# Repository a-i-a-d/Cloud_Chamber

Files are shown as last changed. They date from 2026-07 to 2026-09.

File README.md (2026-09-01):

# Peltier based Cloud Chamber

<p float="left">
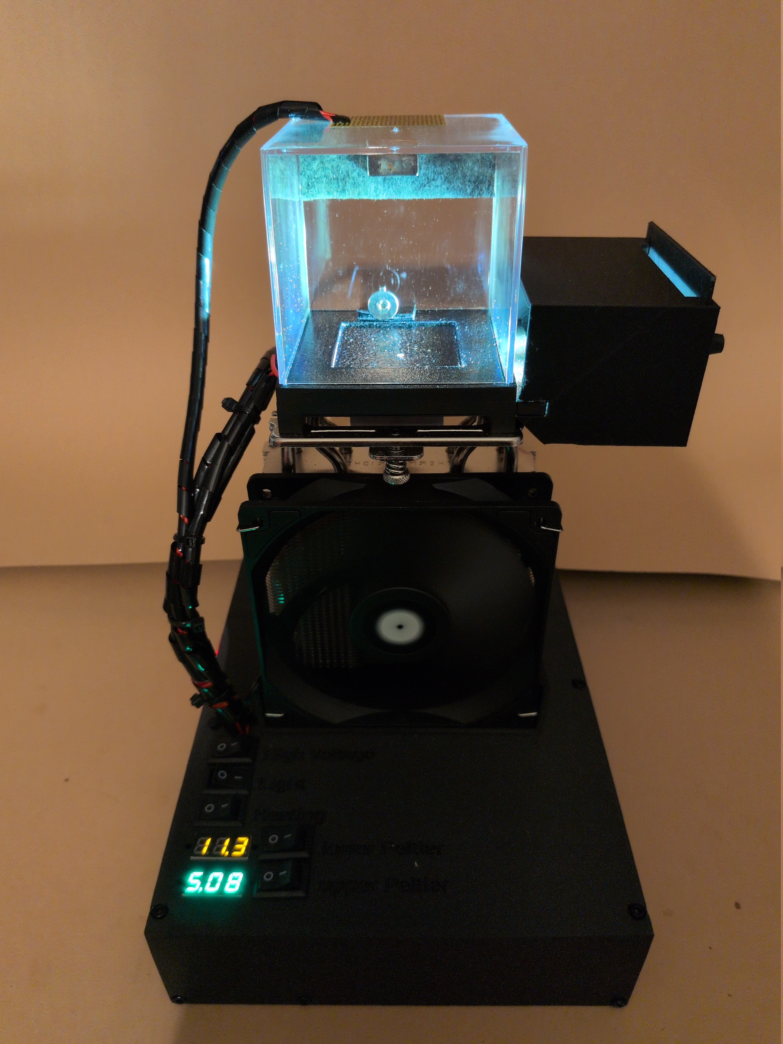
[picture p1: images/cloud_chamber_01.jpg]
 
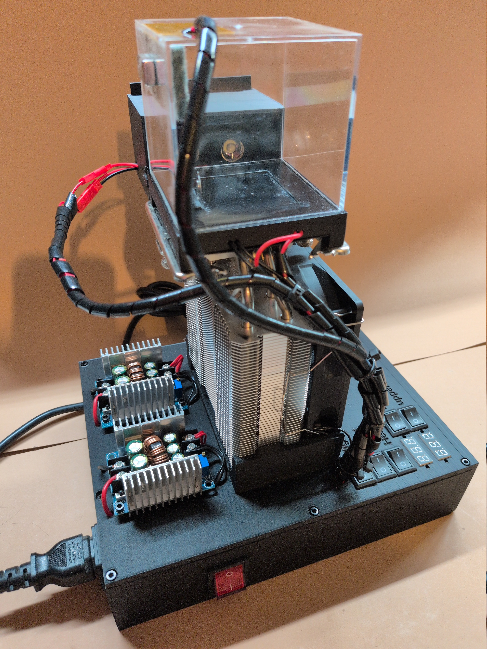
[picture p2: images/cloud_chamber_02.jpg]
 
</p>

This project is the documentation on how I built a Peltier element based cloud chamber. The motivation came from having most of the required parts laying around, and since it works quite well, here are instructions on how it is made.

## WARNING

__This project requires to work with 220V, which can be deadly. Do not attempt to build it if you are not familiar in dealing with mains voltage!__

## Important Notes

- The Peltier elements I used did not consume the wattage according to the specs, so I assume them to be of inferior quality, and therefore will not provide links to where I got them. They do the job, but if they would work according to specs, they should provide even greater cooling.
- This project was not planned, but rather built as a proof of concept to see if the concept works at all, so there are many things that can be improved or changed, e.g. less glueing.
- I did not make use of a high voltage field, it did not seem necessary but might be added at some point in the future. Everything is prepared for it (switch, location for power adapter), so it shouldn't be hard to add it.
- Pictures in this document were taken at different build stages and might not be fully accurate, since I added e.g. the light part later on.

## Table of Contents

- [Parts](https://github.com/a-i-a-d/Cloud_Chamber#parts)
  - [To be Bought](https://github.com/a-i-a-d/Cloud_Chamber#to-be-bought)
  - [To be Printed](https://github.com/a-i-a-d/Cloud_Chamber#to-be-printed)
  - [Other Things Required](https://github.com/a-i-a-d/Cloud_Chamber#other-things-required)
- [Power Schematics](https://github.com/a-i-a-d/Cloud_Chamber#power-schematic)
- [Assembly](https://github.com/a-i-a-d/Cloud_Chamber#assembly)
  - [1. Case Bottom](https://github.com/a-i-a-d/Cloud_Chamber#1-case-bottom)
  - [2. Adjust Voltages](https://github.com/a-i-a-d/Cloud_Chamber#2-adjust-voltages)
  - [3. Case Cover - Under Side](https://github.com/a-i-a-d/Cloud_Chamber#3-case-cover---under-side)
  - [4. Case Cover - Upper Side](https://github.com/a-i-a-d/Cloud_Chamber#4-case-cover---upper-side)
  - [5. Assemble Cooling Tower](https://github.com/a-i-a-d/Cloud_Chamber#5-assemble-cooling-tower)
  - [6. Add Heating Element](https://github.com/a-i-a-d/Cloud_Chamber#6-add-heating-element)
  - [7. Add lights](https://github.com/a-i-a-d/Cloud_Chamber#7-add-lights)
  - [8. Attach Cooling Tower](https://github.com/a-i-a-d/Cloud_Chamber#8-attach-cooling-tower)
  - [9. Connect Cooling Tower](https://github.com/a-i-a-d/Cloud_Chamber#9-connect-cooling-tower)
  - [10. Connect Case Cover to Bottom](https://github.com/a-i-a-d/Cloud_Chamber#10-connect-cover-to-bottom)
- [Usage]()
  - [Adjust Peltier Voltage]()
  - [Prepare Chamber]()
  - [Running the system]()
- [Notes](https://github.com/a-i-a-d/Cloud_Chamber#notes)

# Parts

## To be bought

I had some parts laying around, but for the sake of completeness, I created a list with all parts and their price in Aug 2026 on Amazon.
The total value of the parts is about 250 Euro. Here a list with links.

| Part | Amazon Link | Image | Notes |
| --- | --- | --- | --- |
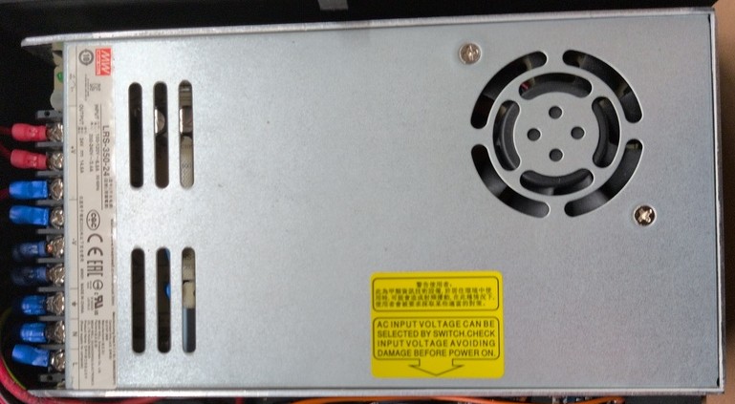
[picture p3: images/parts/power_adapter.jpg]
power-adapter
| Power adapter 220V->24V | [Amazon](https://www.amazon.de/Meanwell-Biltron-Schaltnetzteil-geschlossene-Struktur/dp/B07SVH2H3G/ref=sr_1_30) |  |  |
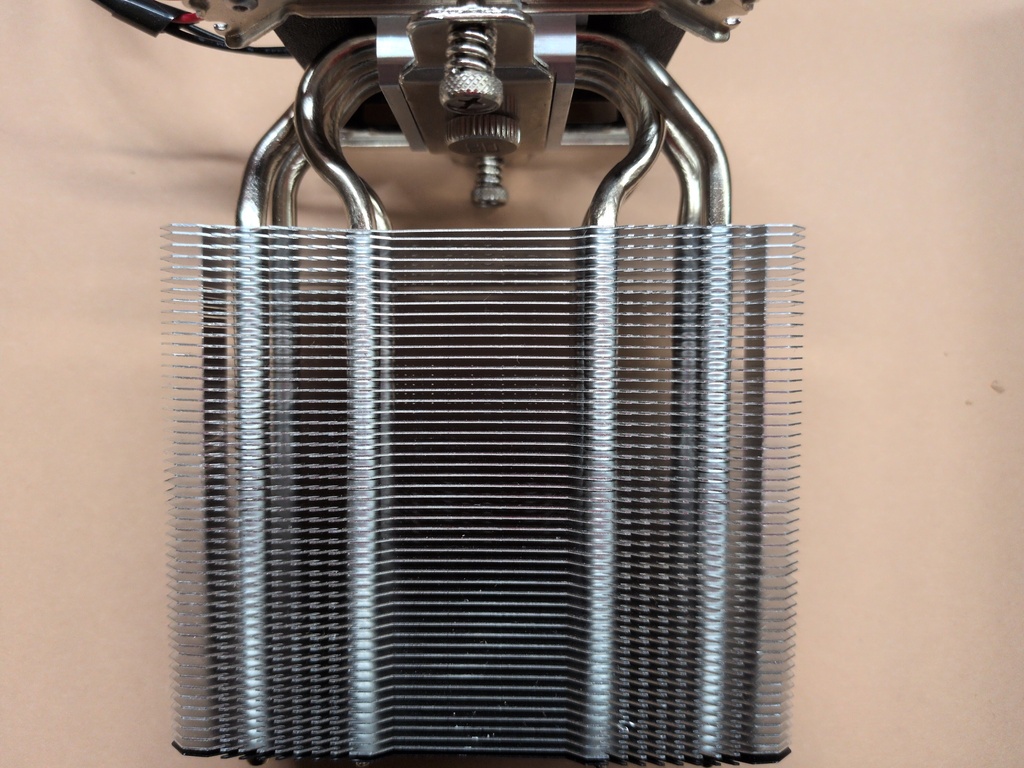
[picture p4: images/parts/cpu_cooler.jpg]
cpu-cooler
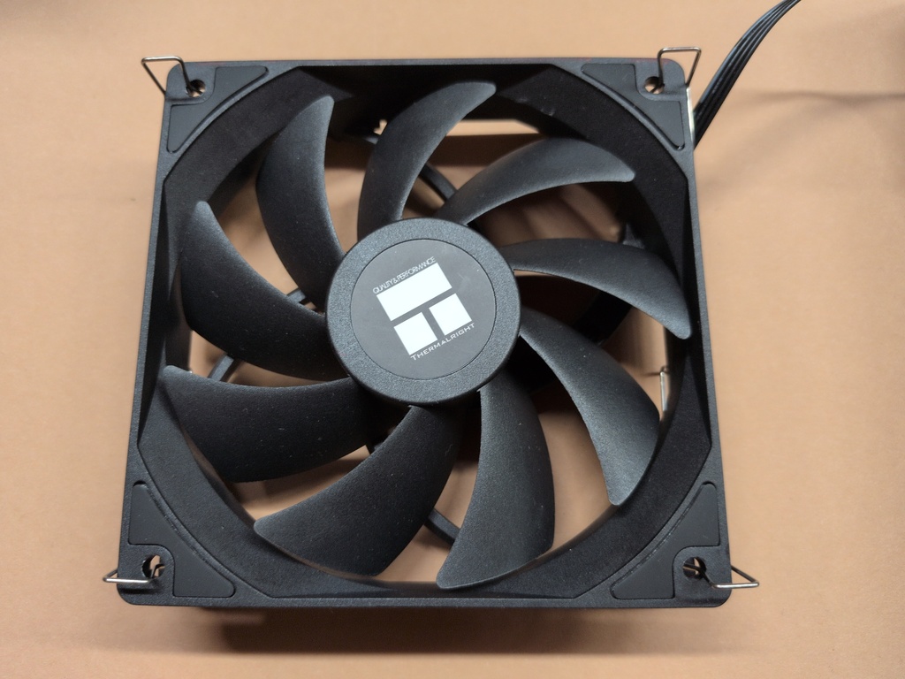
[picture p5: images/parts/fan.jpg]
fan
| 1x CPU Cooler with Fan | [Amazon](https://www.amazon.de/dp/B0FMRXDHD6?ref=ppx_yo2ov_dt_b_fed_asin_title&th=1) | <br> |  |
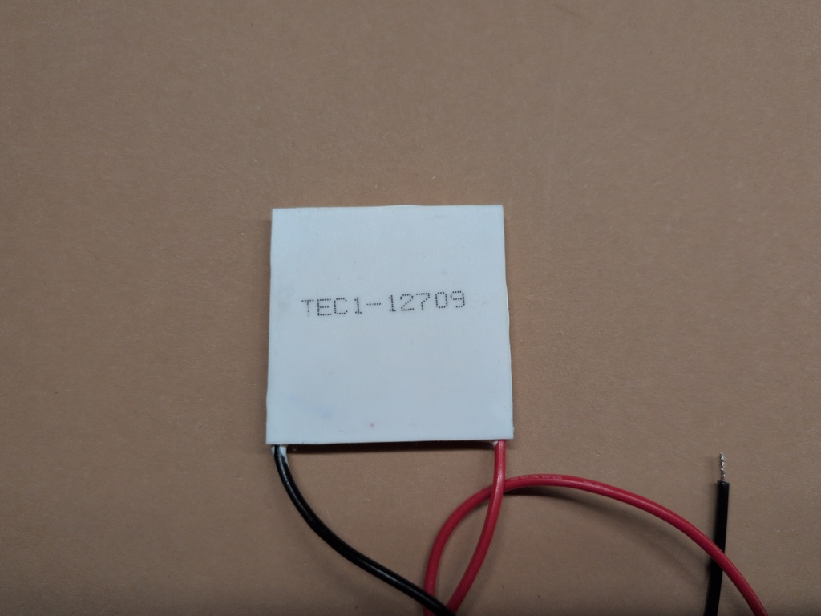
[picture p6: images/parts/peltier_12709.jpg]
peltier-12709
| 1x Peltier 12709 |  |  |  |
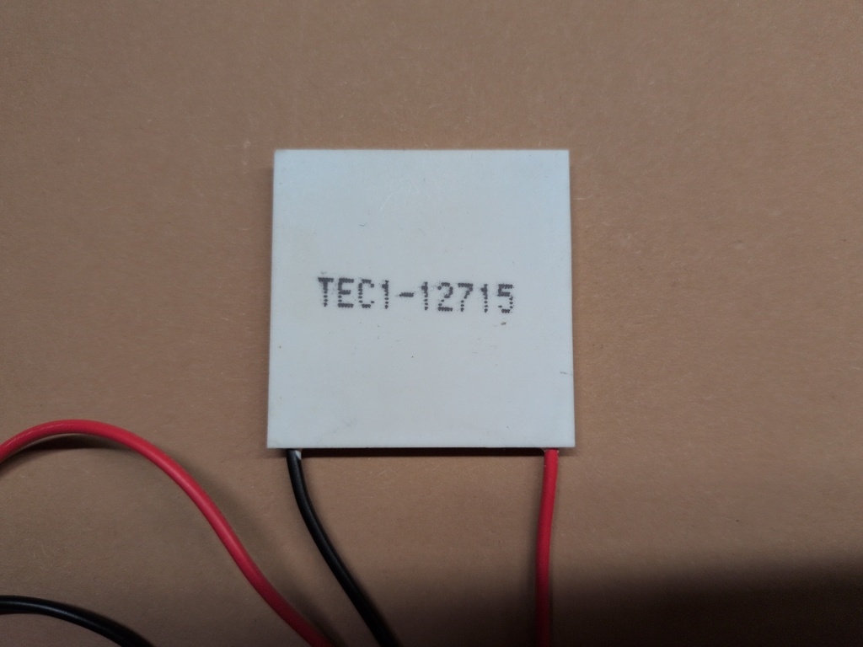
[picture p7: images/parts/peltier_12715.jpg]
peltier-12715
| 1x Peltier 12715 |  |  |  |
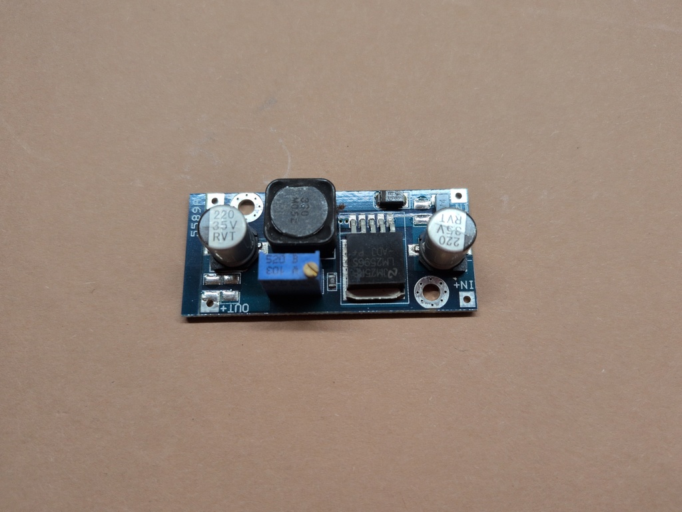
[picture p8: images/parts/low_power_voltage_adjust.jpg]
low-power-voltage-adjust
| 3x Low Power Voltage Converter | [Amazon](https://www.amazon.de/Yizhet-Stromversorgung-Abw%C3%A4rtswandler-Einstellbares-Abw%C3%A4rtsmodul/dp/B0823P6PW6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) |  |  |
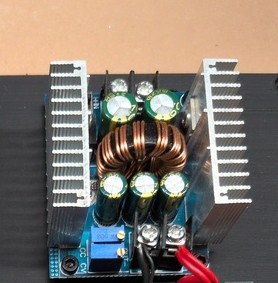
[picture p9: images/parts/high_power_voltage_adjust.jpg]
high-power-voltage-adjust
| 2x High Power Voltage Converter | [Amazon](https://www.amazon.de/dp/B09LLPQHCF?ref=ppx_yo2ov_dt_b_fed_asin_title) |  |  |
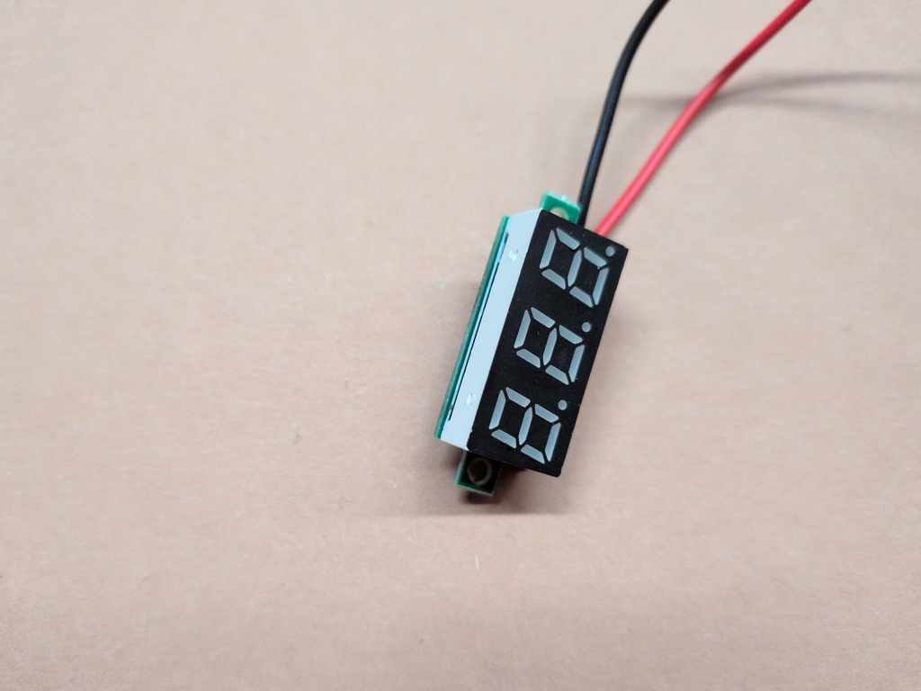
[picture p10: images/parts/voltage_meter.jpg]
voltage meter
| 2x simple voltage meters | [Amazon](https://www.amazon.de/dp/B082ZLRY1Y?th=1) |  |  |
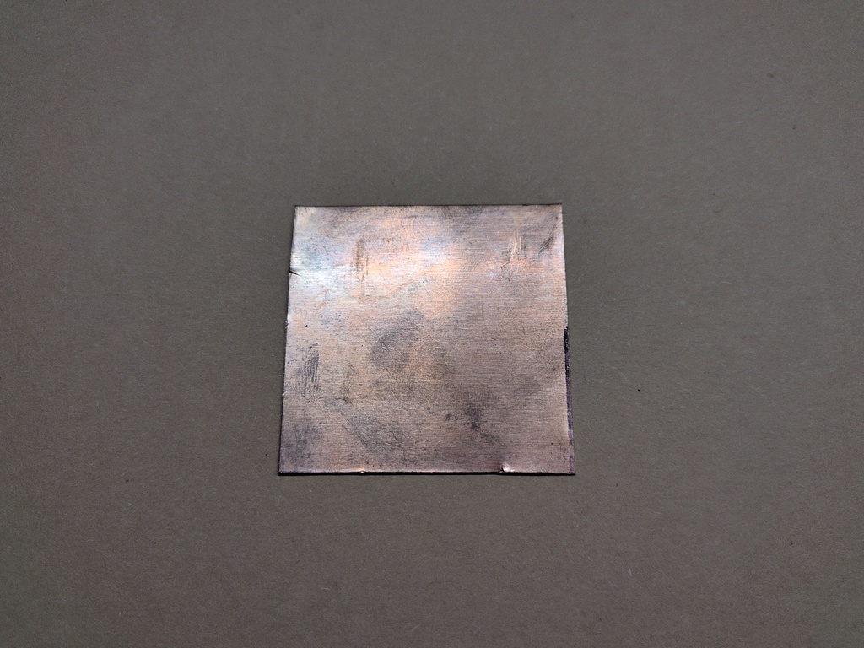
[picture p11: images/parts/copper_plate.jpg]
copper-plate
| Copper Plate 5x5x0.3cm | [Amazon](https://www.amazon.de/dp/B098RTDXQK?ref=ppx_yo2ov_dt_b_fed_asin_title&th=1) |  | The image is not of the actual part, but a thinner plate |
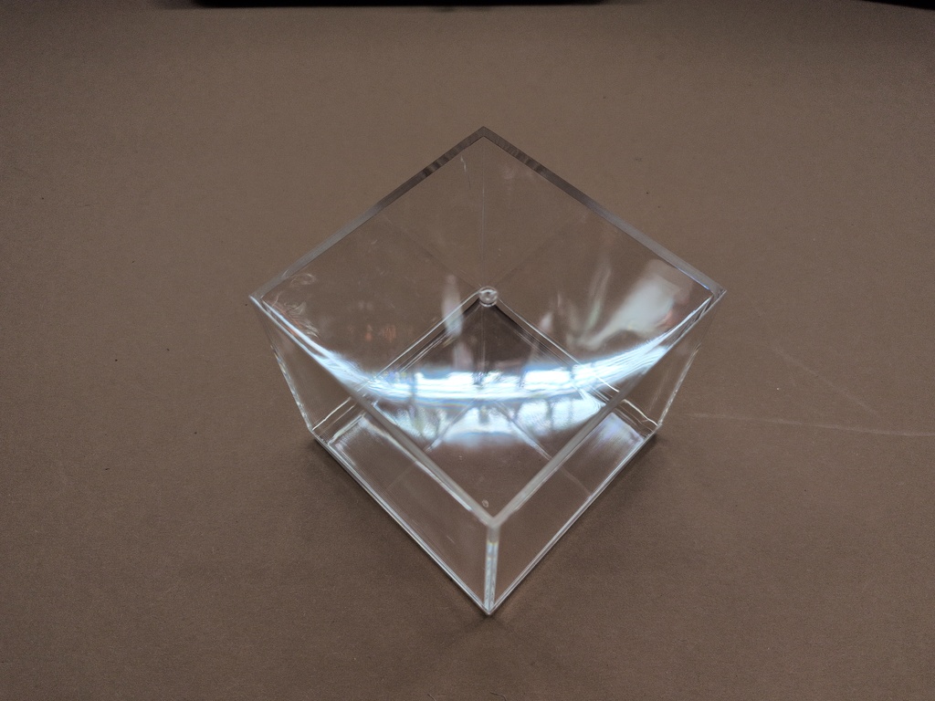
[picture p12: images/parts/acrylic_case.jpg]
acrylic-case
| Acrylic Case 8x8x8cm | [Amazon](https://www.amazon.de/Pilikoll-Transparent-Geschenkbox-transparentf%C3%BCr-Aufbewahrung/dp/B0FVSGY3C1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) |  |  |
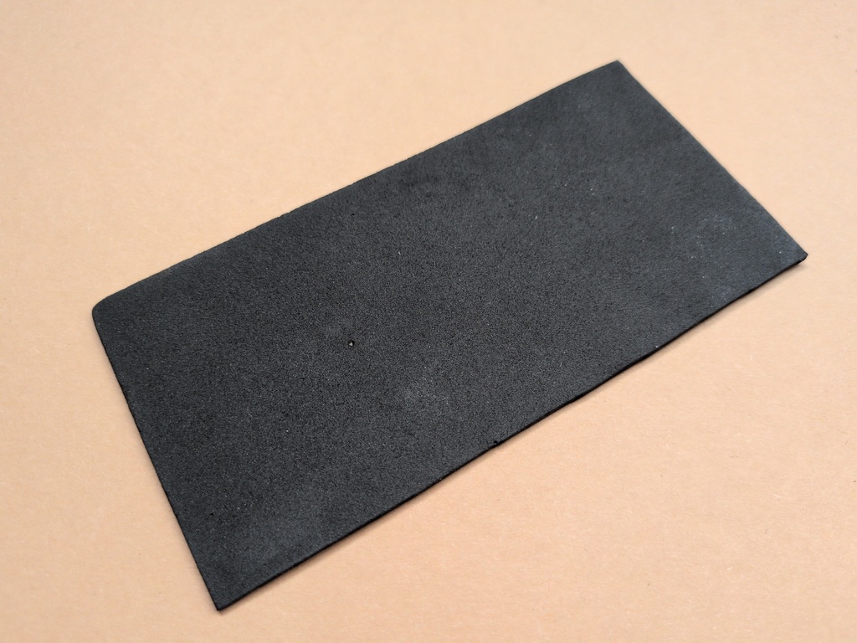
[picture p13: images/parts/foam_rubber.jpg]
foam-rubber
| Foam rubber 2mm | [Amazon](https://www.amazon.de/dp/B07JNZB8X1?ref=ppx_yo2ov_dt_b_fed_asin_title&th=1) |  |  |
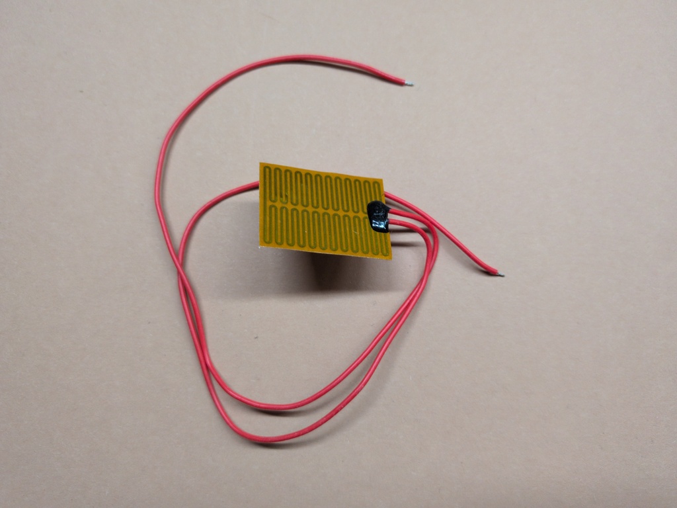
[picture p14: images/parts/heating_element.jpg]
heating-element
| Heating Element | [Amazon](https://www.amazon.de/dp/B0CTTNP7P9?ref=ppx_yo2ov_dt_b_fed_asin_title) |  |  |
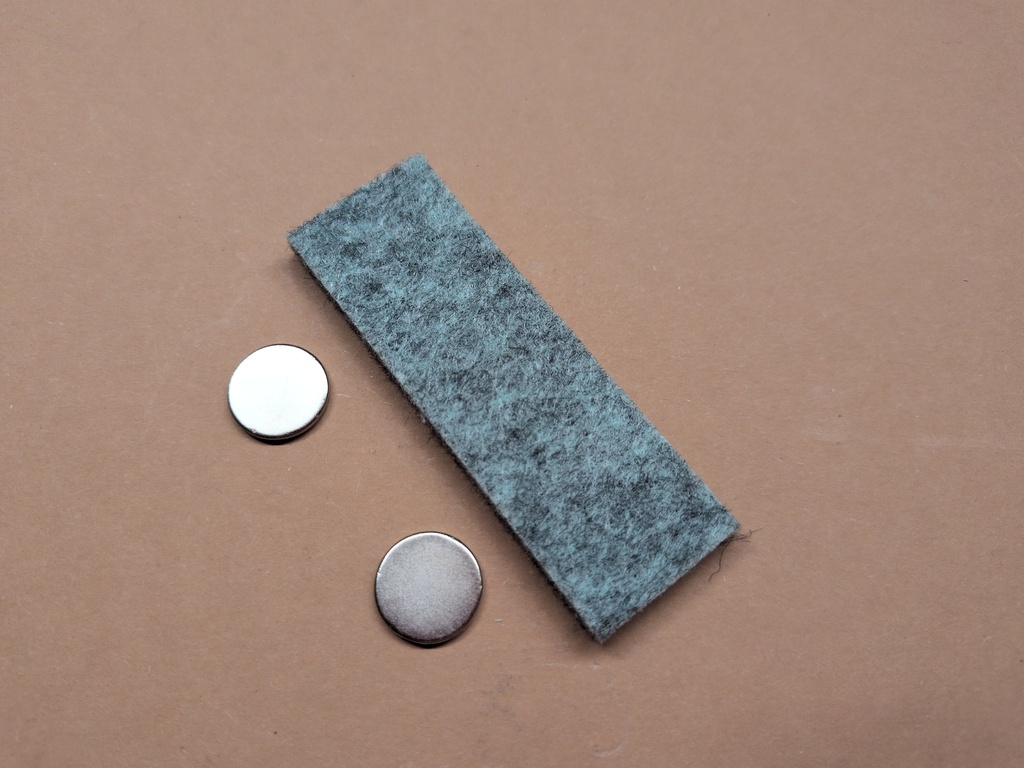
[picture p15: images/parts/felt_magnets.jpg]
felt-magnets
| Felt | [Amazon](https://www.amazon.de/dp/B00WLSX5QU?ref=ppx_yo2ov_dt_b_fed_asin_title&th=1) |  |  |
| Magnets | [Amazon](https://www.amazon.de/-/en/Wukong-Neodymium-Suitable-Whiteboards-Creative/dp/B0CP3N6QV3/ref=sr_1_36) | felt-magnets |  |
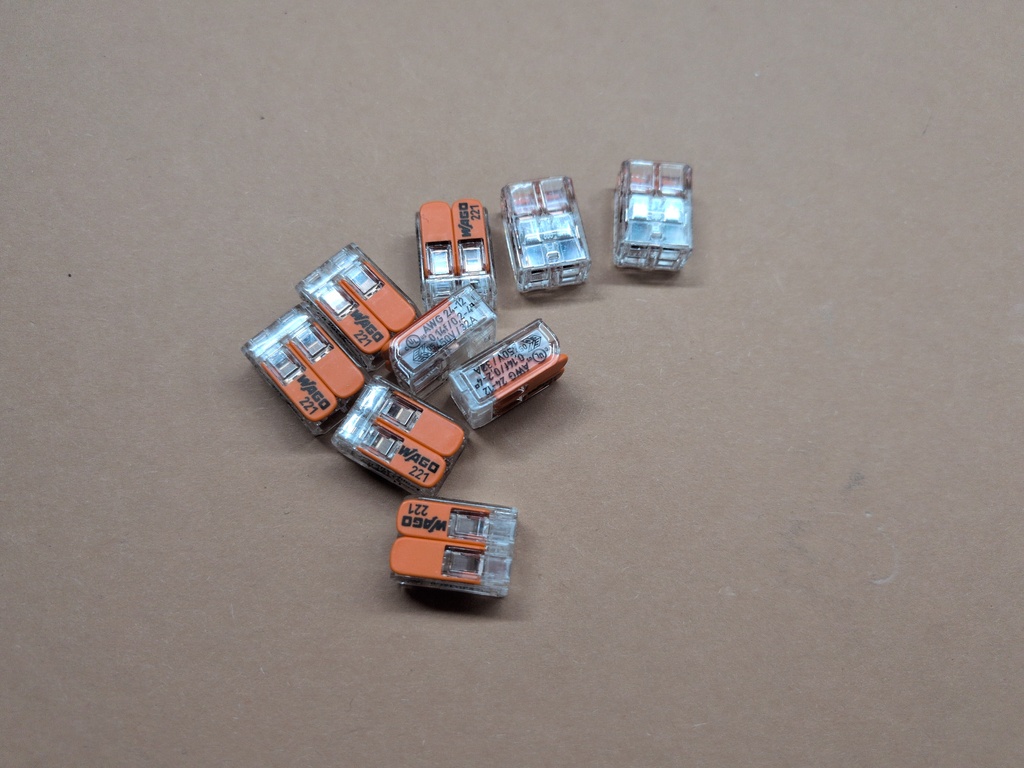
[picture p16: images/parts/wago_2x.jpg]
wago-2x
| 12x WAGO Connector 2x | [Amazon](https://www.amazon.de/Wago-221-412-996-016-Verbindungsklemme-flexibel/dp/B09VZYVWBX/ref=sr_1_3_mod_primary_new) |  |  |
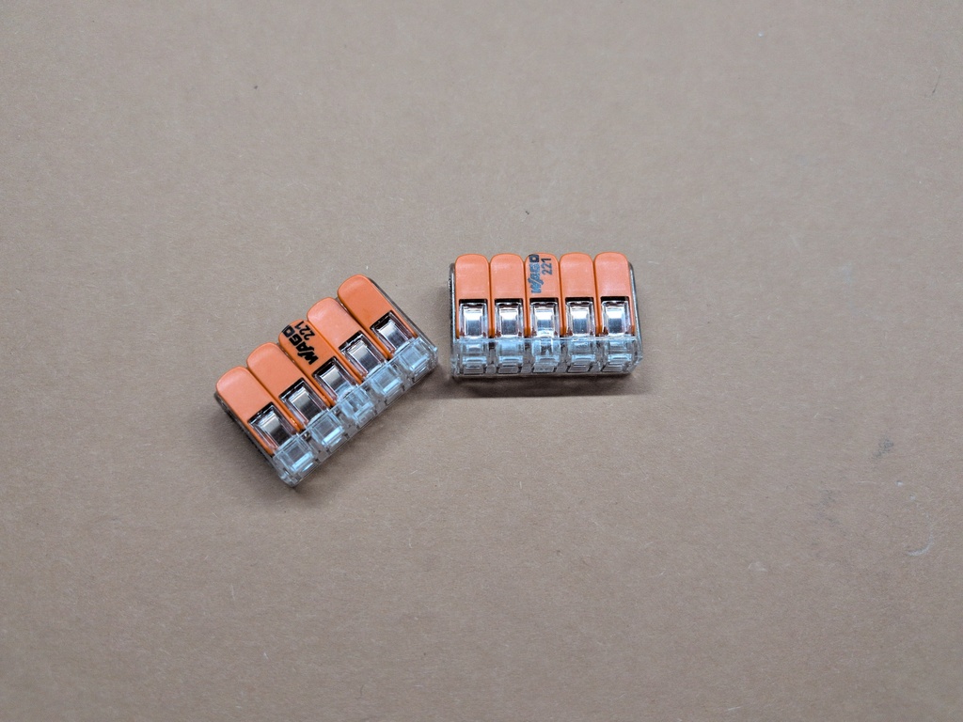
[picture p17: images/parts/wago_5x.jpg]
wago-5x
| 2x WAGO Connector 5x | [Amazon](https://www.amazon.de/Wago-221-415-Verbindungsklemme-5-Leiter-Bet%C3%A4tigungshebel/dp/B0107SYYGU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) |  |  |
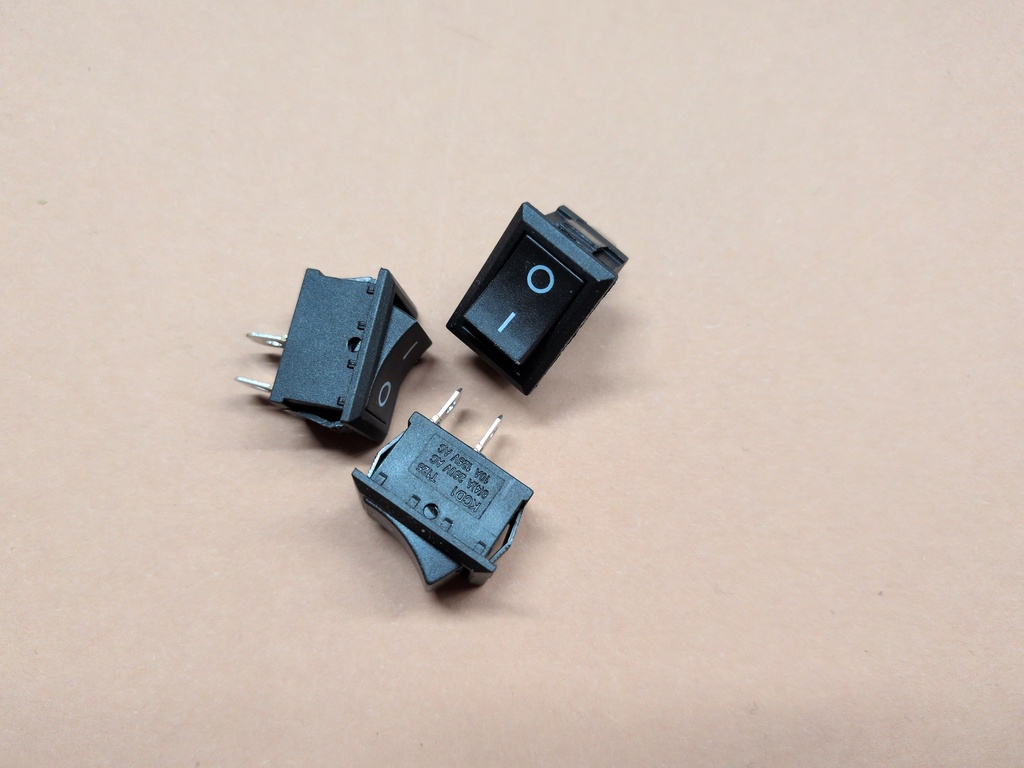
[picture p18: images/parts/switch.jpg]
switch
| 5x Low Power Switches | [Amazon](https://www.amazon.de/VUNIVERSUM-Kippschalter-Wippschalter-Schalter-Modellbau%C2%AE/dp/B07M5QMXDZ/ref=sr_1_16) |  |  |
| LED Spotlights | [Amazon](https://www.amazon.de/dp/B0F9GCK1NC?ref=ppx_yo2ov_dt_b_fed_asin_title) |  |  |
| Thermal pads | [Amazon](https://www.amazon.de/dp/B0B3N7184J?ref=ppx_yo2ov_dt_b_fed_asin_title) |  |  |
| 220V power switch | [Amazon](https://www.amazon.de/Miratic-Unterbeleuchtet-Kippschalter-Schalter-Versorgungsspannung/dp/B0CRBCK8T4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) |  |  |
| 220V power socket | [Amazon](https://www.amazon.de/PNGKNYOCN-IEC320-Stecker-Adapter-Sicherungshalter/dp/B0BWF5M677/ref=sr_1_3) |  |  |
| 6x Insulated flat connectors | | | |
| AWG 10 cable |  |  |  |
| AWG 16 cable |  |  |  |
| AWG 16 cable lugs |  |  |  |
| Insulated flat connectors |  |  |  |
| 4 Screws 4x8mm |  |  |  |
| x Screws 3x8mm |  |  |  |
| x Screws 3x12mm |  |  |  |
| x Screws 2x4mm |  |  |  |
| x Screws 2.5x5mm |  |  |  |
| 8x screw inserts M3x5x5 |  |  |  |
| Silicone |  |  |  |
| Black spray paint |  |  |  |
| Super glue |  |  |  |

## To be printed

All printed parts are openscad code, you can open them with openscad and then directly change variables at the beginning to adjust the screw diameter or part dimensions. Please note that I haven't tested changing them, so this might result in non printable models.

| Part | Image | Link | Notes | 
|---|---|---|---|
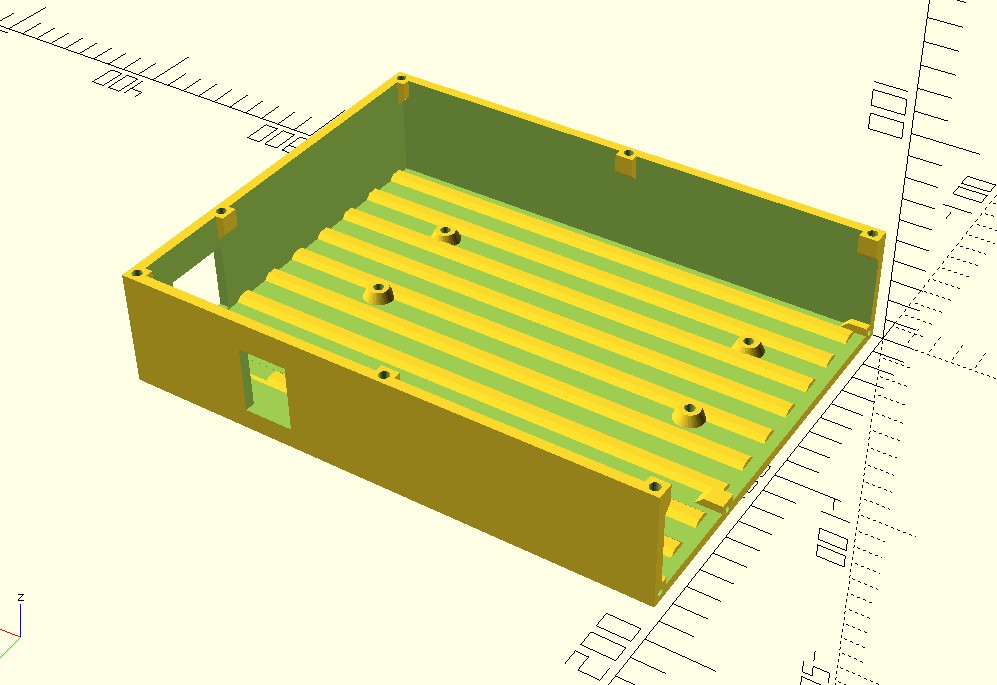
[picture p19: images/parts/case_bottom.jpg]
case-bottom
| Case Bottom |  | [stl](/stl/cloud_chamber_power_case-lower.stl) | best printed standing up with support |
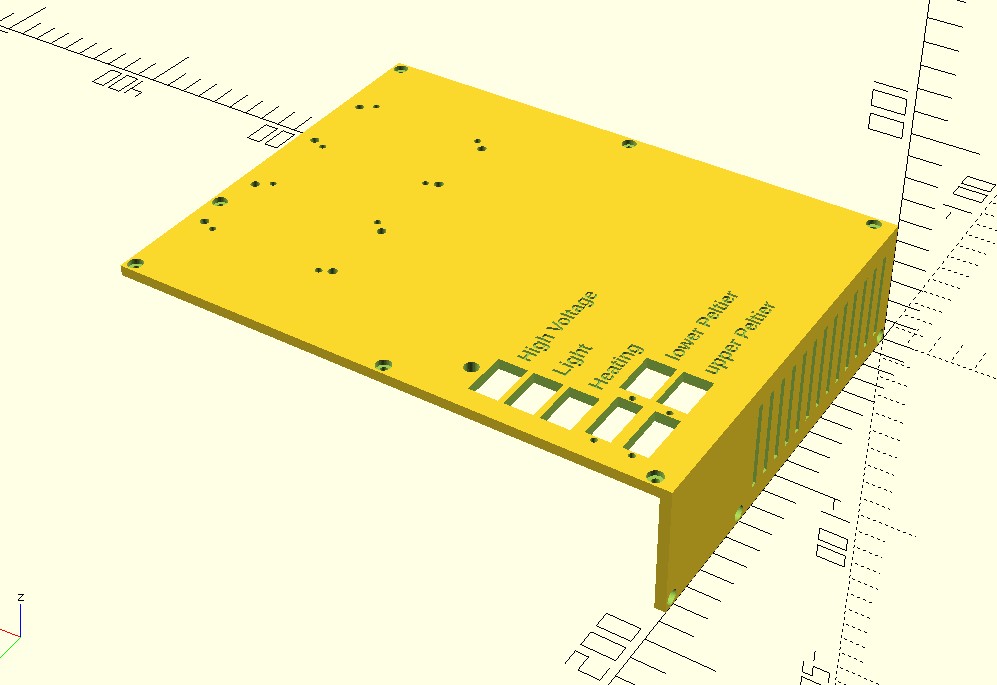
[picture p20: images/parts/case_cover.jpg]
case-cover
| Case Cover |  | [stl](stl/cloud_chamber_power_case-upper.stl) | best printed standing up with support |
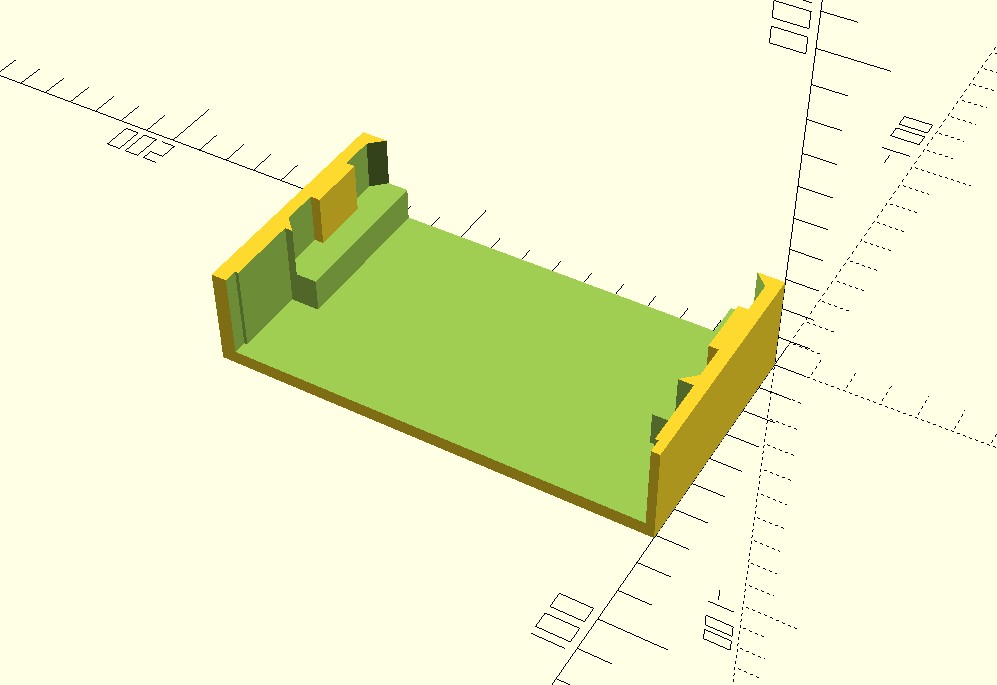
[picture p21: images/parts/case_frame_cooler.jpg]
case-cooler-frame
| Case Cooler Frame |  | [stl](stl/cloud_chamber_top.stl) | |
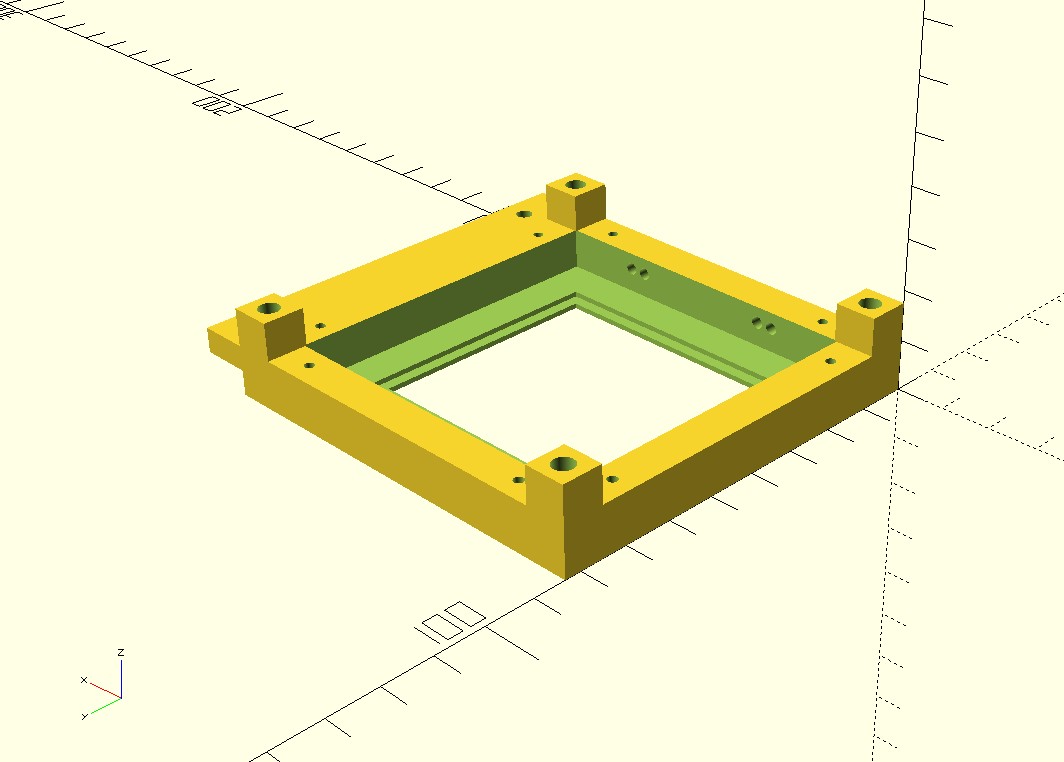
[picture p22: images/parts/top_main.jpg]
top-part
| Top Part |  | [stl](stl/cloud_chamber_cooling_plate-main_body.stl) | |
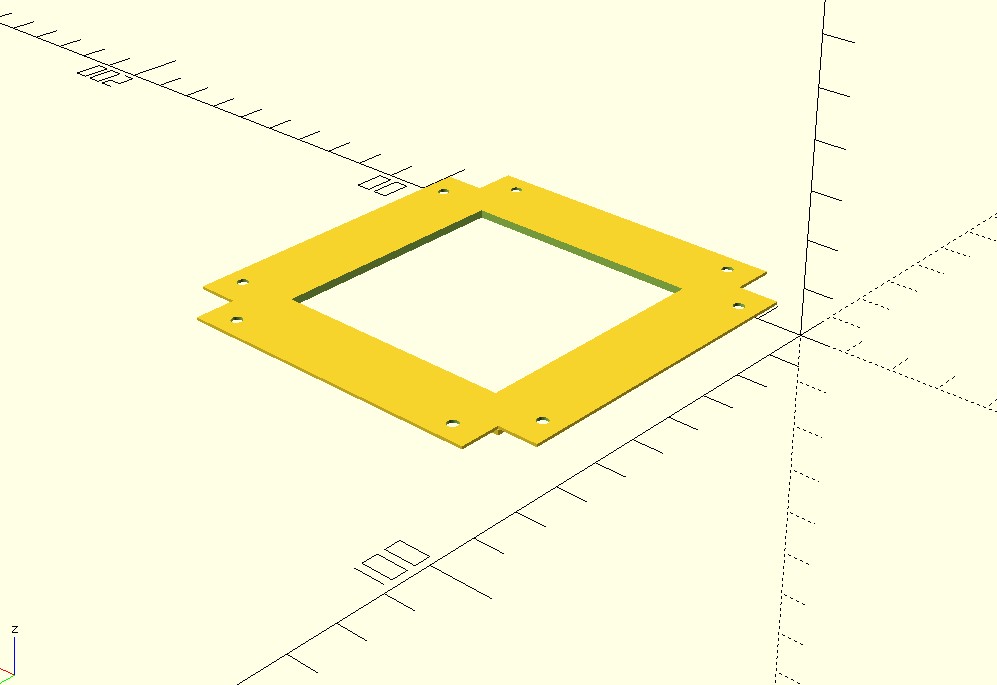
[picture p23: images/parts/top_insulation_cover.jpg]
top-insulation-cover
| Top Insulation Cover |  | [stl](stl/cloud_chamber_cooling_plate-insulation_top.stl) |  |
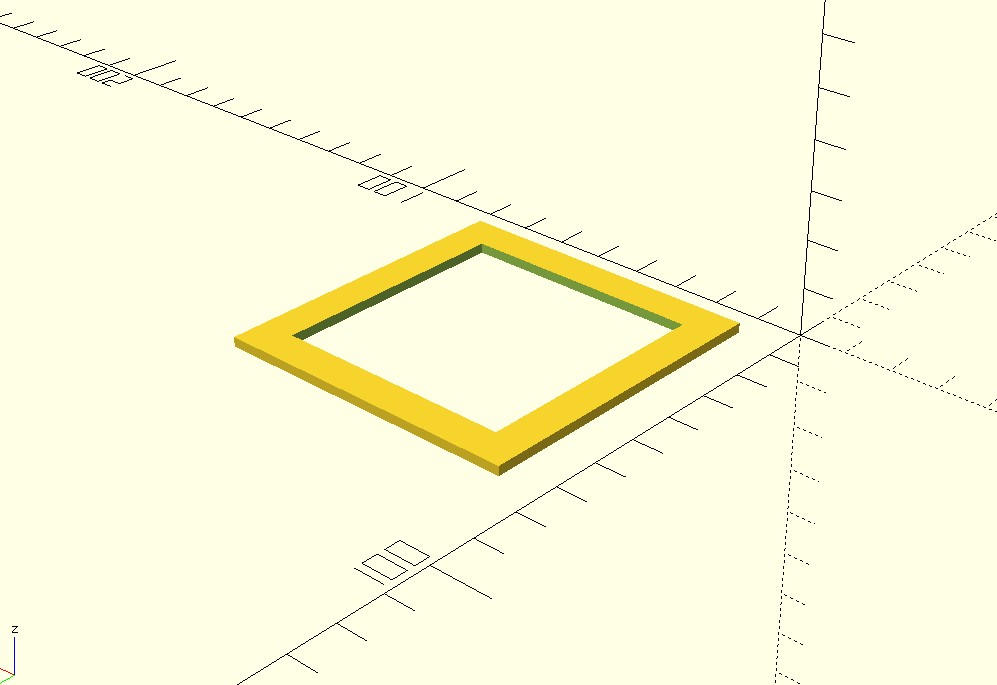
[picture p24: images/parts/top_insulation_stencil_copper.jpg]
top-insulation-stencil-copper
| Top Insulation Stencil Copper |  | [stl](stl/cloud_chamber_cooling_plate-insulation_stencil_coppr.stl) | optional part, only used as stencil for the insulation |
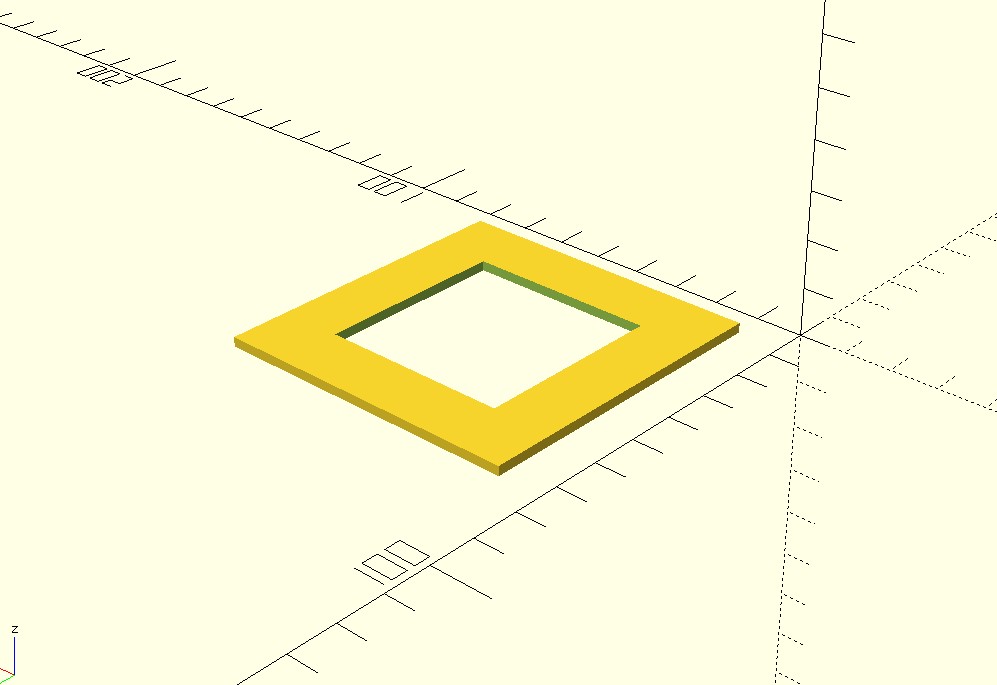
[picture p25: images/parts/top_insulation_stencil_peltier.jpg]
top-insulation-stencil-peltier
| Top Insulation Stencil Peltier |  | [stl](stl/cloud_chamber_cooling_plate-insulation_stencil_peltier.stl) | optional part, only used as stencil for the insulation |
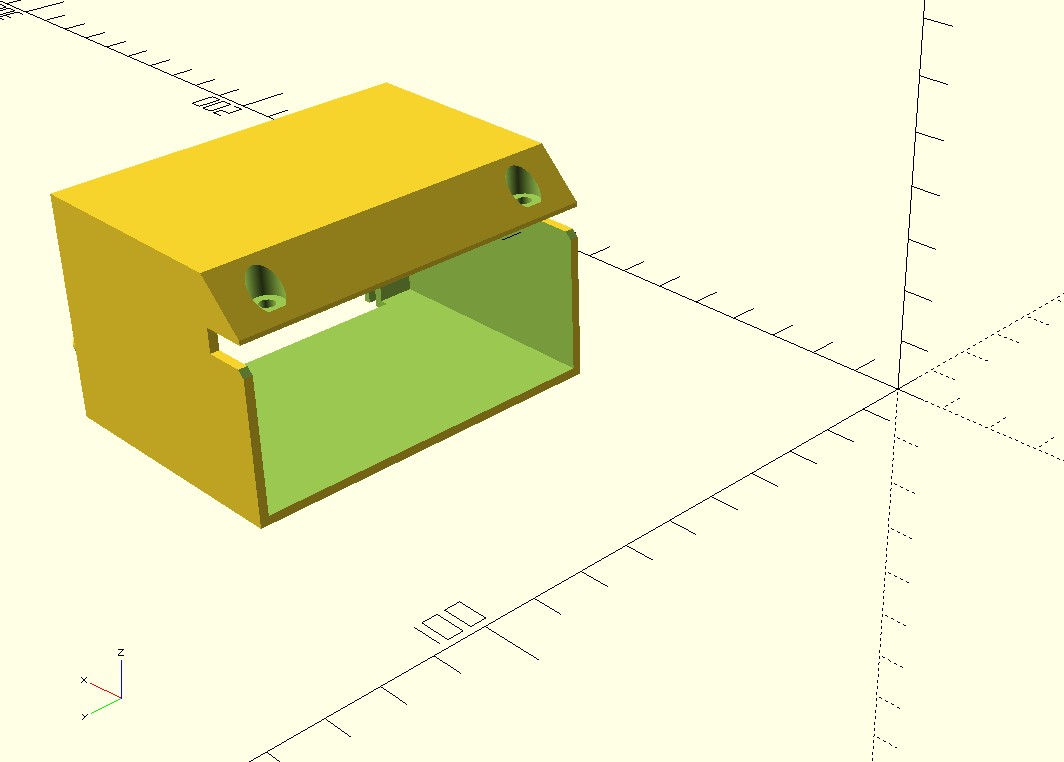
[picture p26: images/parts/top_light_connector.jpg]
light-connector
| Light Connector Box |  | [stl](stl/cloud_chamber_light_case.stl) | |
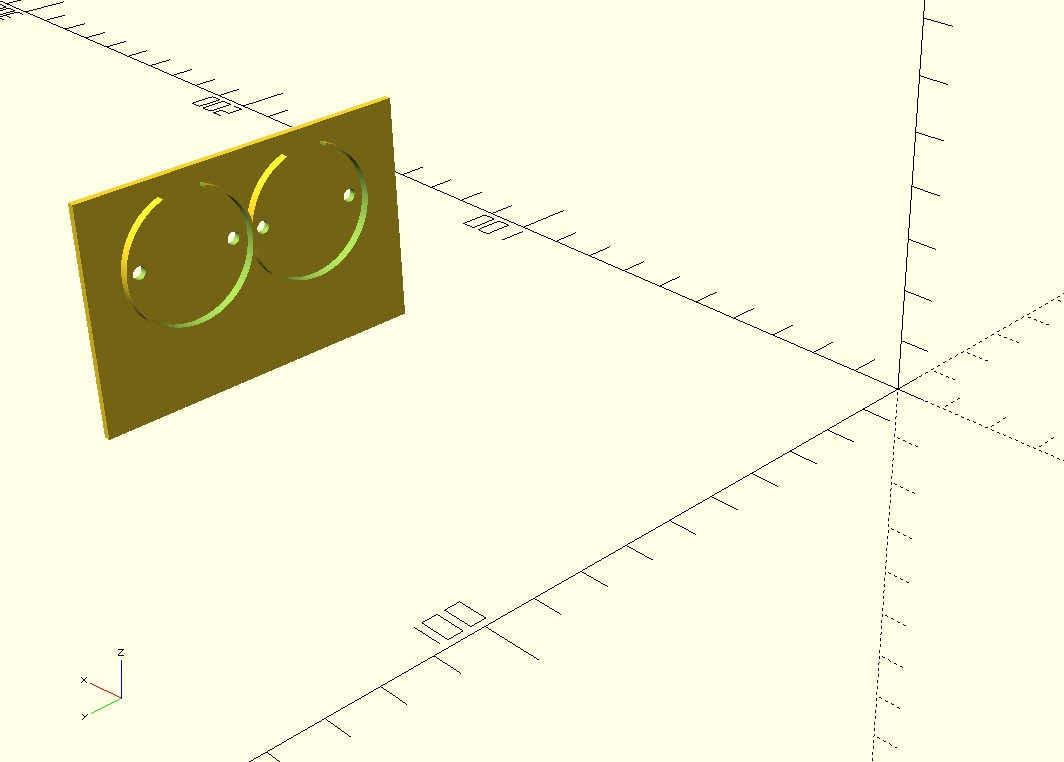
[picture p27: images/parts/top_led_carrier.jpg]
led-carrier
| LED Carrier |  | [stl](stl/cloud_chamber_led_carrier.stl) | |

## Other things required

- Voltage Meter - for adjusting the voltages<br>
- Soldering Iron, for soldering cables to the low power adapters, plugs and switches.

# Power Schematic
A simple diagram showing how everything gets connected. There is not much going on but voltage getting adjusted for different parts.<br>
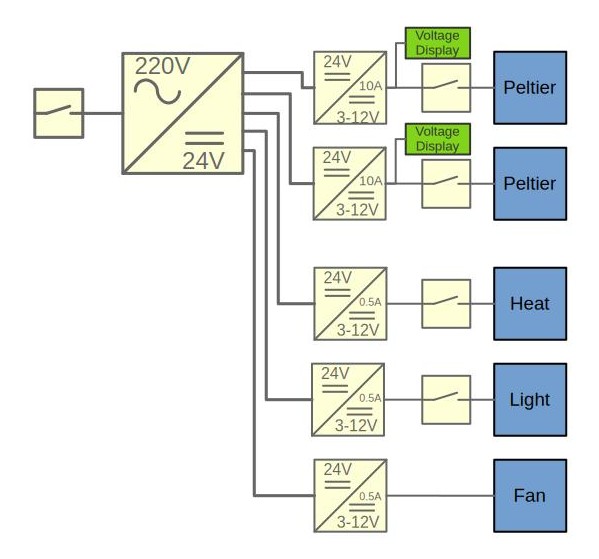
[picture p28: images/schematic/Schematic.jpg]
schematic


# Assembly
Once all parts are printed, the assembly is pretty much straight forward.

## 1. Case Bottom

__Note__: all connections with the 220V->24V voltage adapter have to be done with cable lugs. Don't screw in cables directly!

1.1 Prepare case
- insert the screw inserts into the screw holes of the bottom part of the case with a hot soldering iron.

1.2 Connect voltage adapter with 220V switch and socket
- Screw the 220V socket into the case
- Insert the 220V switch into the case
- Screw the power adapter into the bottom of the case with 4x8 mm screws from below
- Connect N (blue) and L (black) from the 220V socket to the 220V switch using insulated flat connectors and AWG 16 cables
- Connect N (blue) and L (black) from the 220V switch to the N and L connection on the 220V voltage adapter using insulated flat connectors and AWG 16 cables
- Connect E from the 220V socket to the E connection on the 220V voltage adapter using insulated flat connectors and a green-yellow AWG 16 cable
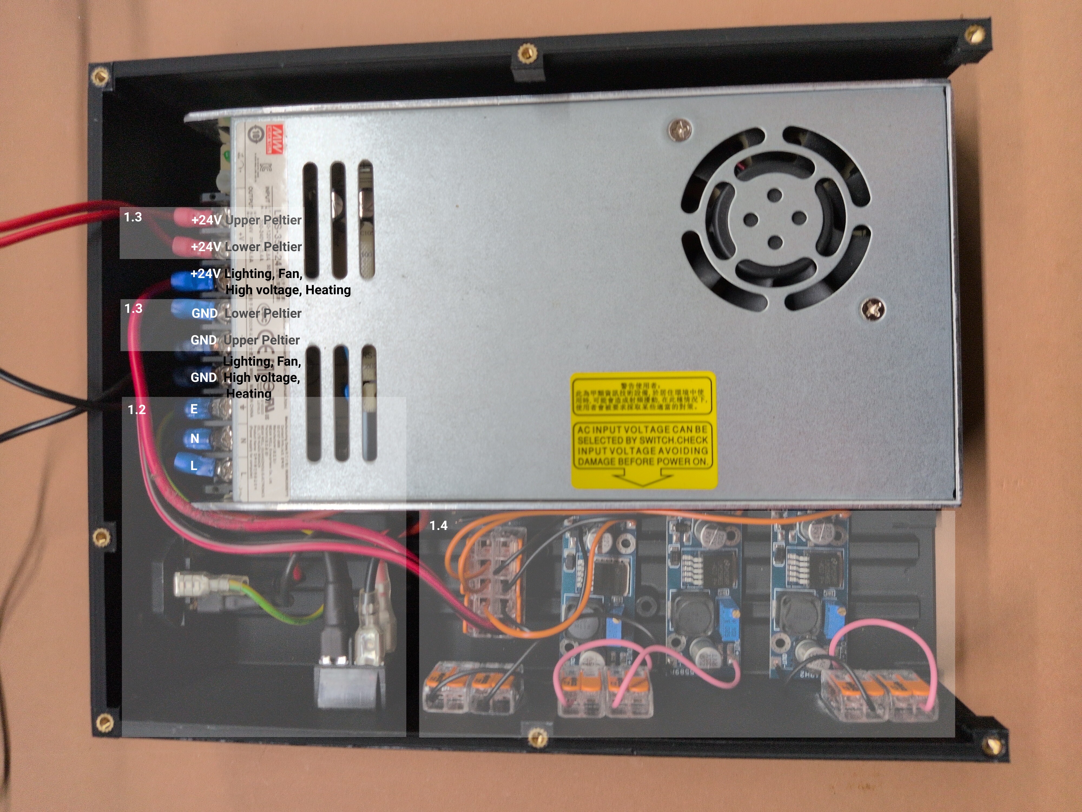
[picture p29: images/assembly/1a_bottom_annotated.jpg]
 

1.3 Add cables for later connection to 24V->3-12V adapters
- Connect 2 (red) AWG 16 cables for the Peltier elements to one of the +24V connectors of the 220V voltage adapter and let them hang loose for now
- Connect 2 (black) AWG 16 cables for the Peltier elements to one of the GND connectors of the 220V voltage adapter and let them hang loose for now

1.4 Install low power adapters

- Glue 2 WAGO-5x connectors onto the square field, one for +12V and one for GND connections
- Connect the remaining +24V connection of the 220V voltage adapter to one 5xWAGO connector with a (red) AWG16 cable
- Connect the remaining GND connection of the 220V voltage adapter to the other 5xWAGO connector with a (black) AWG16 cable
- Solder (red and black) AWG10 cables to the low power adapter input and output connections.
- Screw in the 3 low power voltage adapter with 2.5x5mm screws
- Attach the +V input side of the low power adapters with the 5xWAGO connector that is connected to the 24V+ connection of the 220V voltage adapter
- Attach the GND input side of the low power adapters with the 5xWAGO connector that is connected to the GND connection of the 220V voltage adapter
- Glue 6 2xWAGO connectors onto the side of the case
- Connect the three V+ and three GND output cables of the low voltage adapters with the 6 2xWAGO connectors (one connection per WAGO)
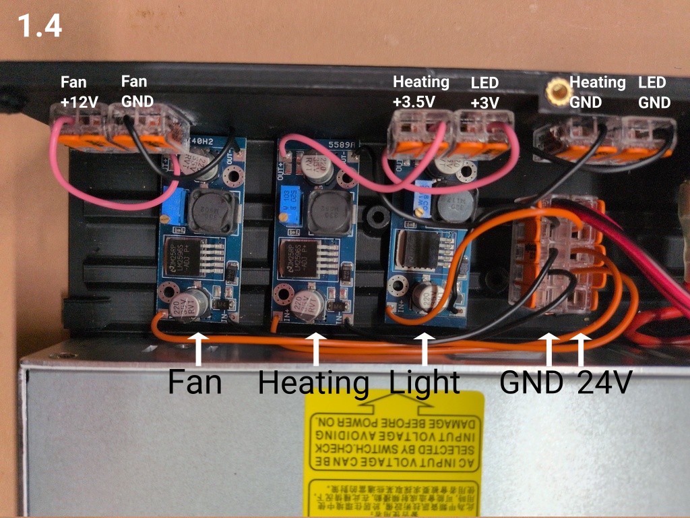
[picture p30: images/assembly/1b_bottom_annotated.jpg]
 

## 2. Adjust Voltages

Connect a voltage meter to the 2x WAGO adapters and adjust the output voltage of the three low voltage adapters using a screw driver.

__WARNING:__ You have to connect the system to mains and switch it on for this step, make sure you never touch the 220V conducting parts!

| Instruction | Image |
|---|---|
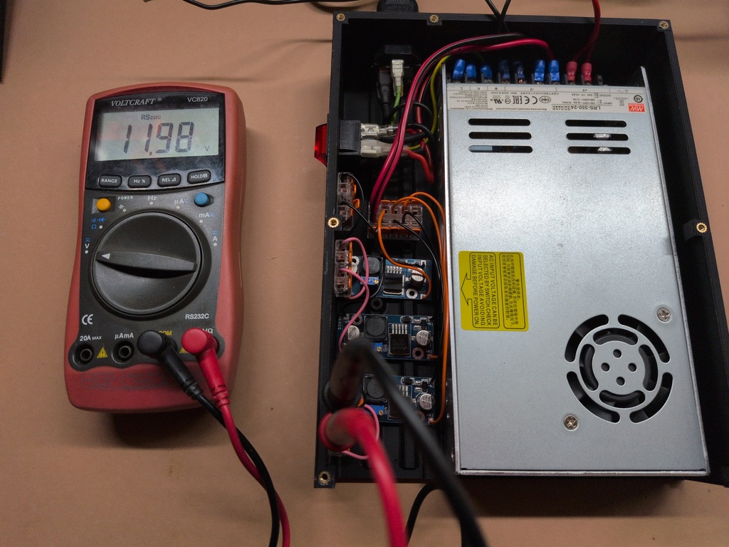
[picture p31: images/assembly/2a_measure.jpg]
| Set 12V for the fan |  |
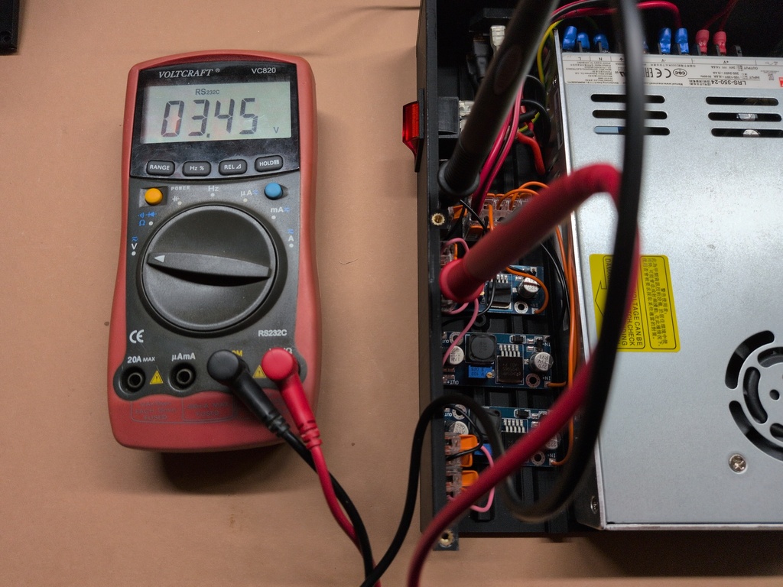
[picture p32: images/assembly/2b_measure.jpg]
| Set 3.5V for the heating element |  |
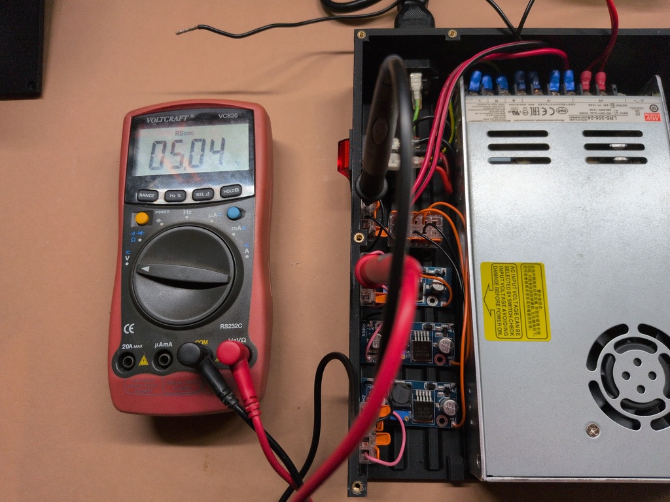
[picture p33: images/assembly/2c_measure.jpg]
| Set 3V, 5V or 12V for the LED lighting<br> (For the LED lights linked in the parts list above, please use 3V. The picture was taken before that was installed) |  |

## 3. Case Cover - Under Side

__NOTE:__ All wires should have their ends soldered before putting them into the WAGO connectors. It's not mandatory, but prevents problems of bad connections

- Glue in 7 WAGO-2x connectors
- Solder 2x AWG16 cables to the 2 Peltier power switches
- Solder 2x AWG10 cables to the Light and Heating switches
- Plug switches in their holes in the cover
- Feed the AWG16 wires from one connection of the Peltier switches through the holes to the high power voltage adapter
- Connect the AWG16 cables from the other Peltier switch connection to the Lower and Upper Peltier WAGO connector (make sure to not mix them up)
- Connect the AWG10 wires of one connection of the Light and Heating switches to the corresponding WAGO connectors
- Leave the 2 AWG10 wires from the other connection of the Light and Heating switches hanging loose (they'll be connected to the case base later)
- Insert mini voltage meters in the holes in the cover and also feed the wires through the holes to the high power voltage adapter
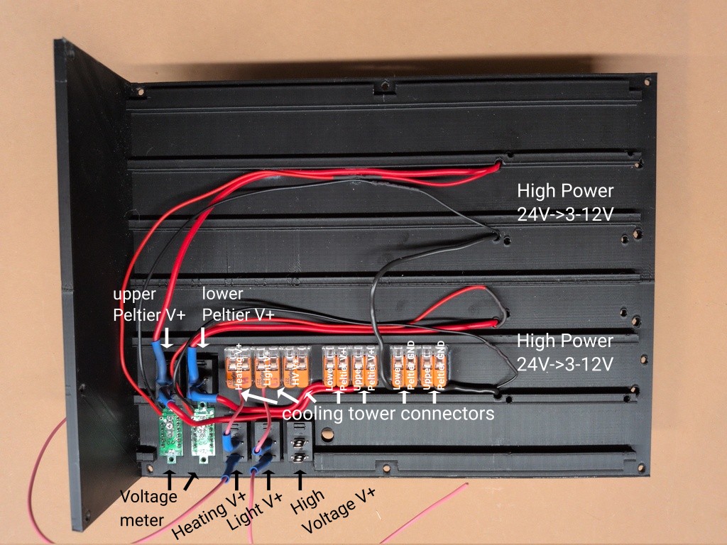
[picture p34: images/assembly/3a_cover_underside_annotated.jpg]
 

## 4. Case Cover - Upper Side

| Instruction | Image |
|---|---|
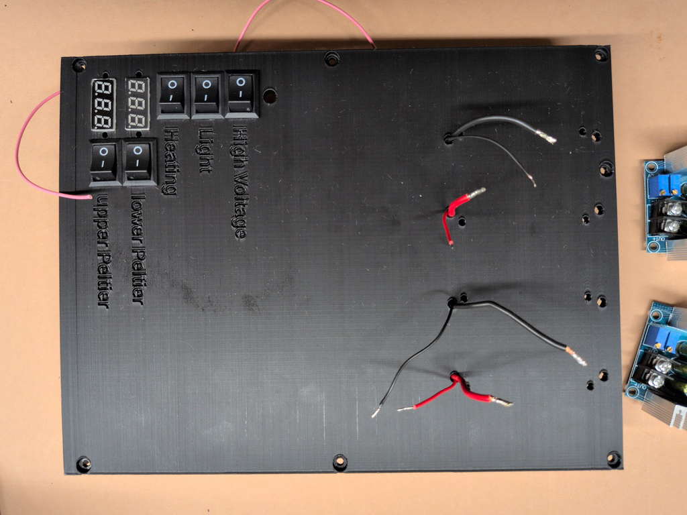
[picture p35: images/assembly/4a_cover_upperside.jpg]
| - Rotate cover and make sure power and voltage meter cables are available |  |
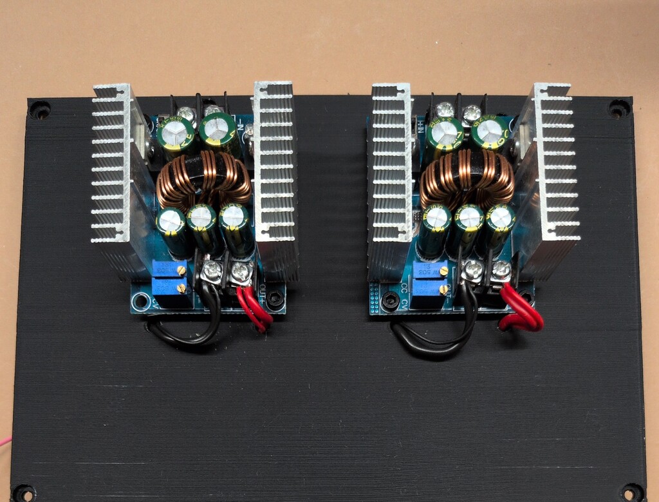
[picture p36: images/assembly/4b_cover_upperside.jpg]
| - Screw in high power voltage converters using 3x12mm screws<br> - Screw in the AWG16 cables and the cables from the voltage meters into the out connectors of the voltage converters (take care of correct polarity) |  |

## 5. Assemble Cooling Tower

The cooling tower consists of the copper plate on top of 2 stacked Peltier elements on the CPU cooler with thermo paste or pad in between (Both worked, I used pads in the final build, since they are less messy). This schematic of the cooling tower shows the different layers:<br>
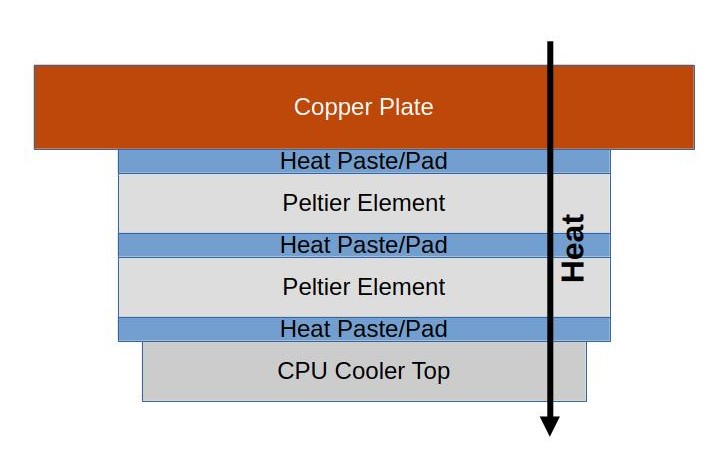
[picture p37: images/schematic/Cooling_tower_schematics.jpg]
schematic
<br>

__Note:__ Usually the side with the printing is the cooling side of the Peltier elements. But double check if that is true for the ones you use.

| <div style="width:400px">Instruction</div> | <div style="width:400px">Image</div> |
|---|---|
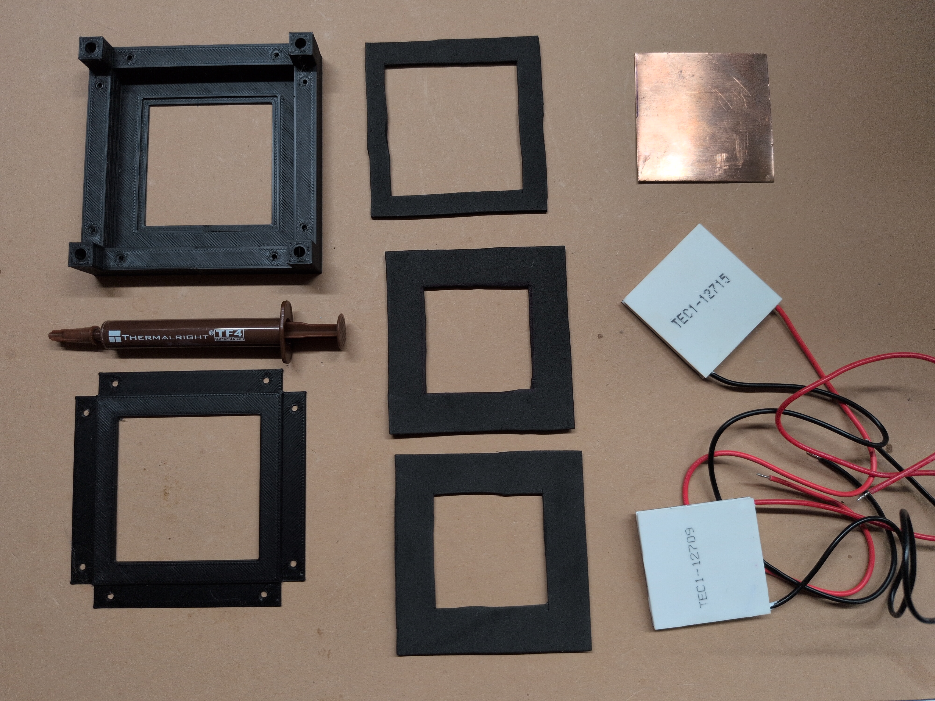
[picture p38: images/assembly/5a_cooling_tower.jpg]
| - Overview of used parts for the top |  |
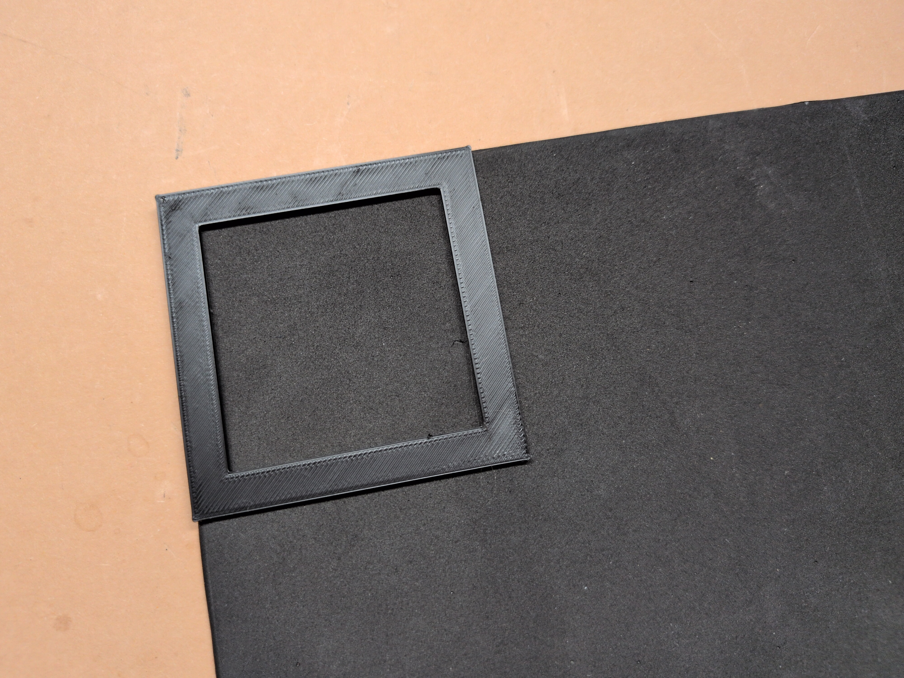
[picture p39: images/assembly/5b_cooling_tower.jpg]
| - Use the stencils to mark cutout from the foam rubber |  |
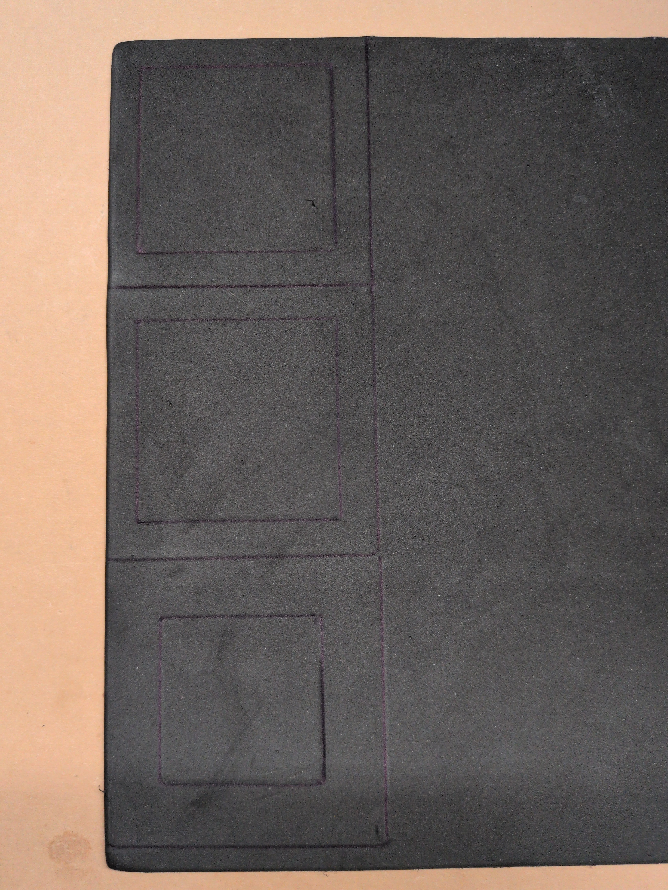
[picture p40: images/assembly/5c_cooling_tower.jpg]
| - Create two cutouts for the peltier elements and one for the copper plate  |  |
| - Put silicone into the indentation in the top main part |  |
| - Glue in the copper plate.<br> __Make sure there are no gaps, the silicone acts as insulation and to prevent liquid from leaking out from the cloud chamber__<br> -Let it fully cure before continuing<br> - Once cured, put it the other way around and let some isopropanol sit on top of the cover to make sure nothing leaks |  |
| - Place the rubber foam insulation for the copper plate around it.<br> It has to fit smoothly and must not bend or have too large gaps |  |
| - Add the thermal pad or paste onto the copper plate |  |
| - Put one rubber foam insulation for the Peltier elements on the copper plate<br> - Feed the wires from the 12709 Peltier element through the holes on the side of the top main part<br> - Place the Peltier element with the printing onto the thermal pad/paste. |  |
| - Add the thermal pad or paste onto the Peltier element |  |
| - Feed the wires from the 12715 Peltier element through the other two holes on the side of the top main part<br> - Place the Peltier element with the printing towards the thermal paste/pad |  |
| - Put the second rubber foam insulation for the Peltier elements around the Peltier element |  |
| - Close the stack with the Top Insulation Cover |  |
| - Add the thermal pad or paste onto the Peltier element |  |
| - Screw the brackets of the CPU cooler onto the Top Main Part<br> - Attach the CPU cooler to the brackets with the two thumb screws on the cooler<br> __Screw them tight, so there is good thermal conductivity, but always check the top, so the printed part does not start cracking from the pressure__ | <br> <br>  |
| - Turn the whole cooling tower over and spray the top with black spray paint |  |

## 6. Add Heating Element

| Instruction | Image |
|---|---|
| - Stick the heating element on top of the acrylic case<br> - Fixate a piece of felt in the acrylic cover using the magnets |  | 

## 7. Add lights

| Instruction | Image |
|---|---|
| - Print the Light Connector Box and the LED Carrier<br> - slide the carrier into the box and screw in one or two 2mm screws to fixate the carrier |  |
| - Screw the LED spot lights onto the carrier and feed their cables through the small opening of the box  |  |
| - Attach the box to the cooling tower<br> - Fixate it with screws if necessary<br> The height of the LED spot lights can be adjusted by moving the LED carrier and fixating it with the screws from behind |  |

## 8. Attach Cooling Tower

| Instruction | Image |
| --- | ----- |
| - Glue the cooling tower frame on the case cover |  |
| - Stick the cooling tower with the attached fan into the frame<br> - Feed the cables from the Peltier elements, the heating element and the lights through the hole beside the tower frame in the case cover | <br>  | 

## 9. Connect Cooling Tower
- Connect the V+ wires of the Peltier elements to the corresponding WAGO connectors
- Connect the GND wires of the Peltier elements to the corresponding WAGO connectors
- Connect the V+ wires from the LEDs and heating element with the corresponding WAGO connectors<br>(Please note that in the picture, the GND cable wrongly is connected. The cable is supposed to be red, not black)
- Leave the GND wires from the LEDs and heating element hanging loose
 

## 10. Connect Cover to Bottom
- Connect the loose cables from the top on the cover with the corresponding connectors in the base
  - Light V+ (red wire from the power switch)
  - Light GND (black wire from the cooling tower)
  - Heating V+ (red wire from the power switch)
  - Heating GND (black wire from the cooling tower)
  - Fan V+ (wire from the cooling tower)
  - Fan GND (wire from the cooling tower)
 
- Stick the 24V+ AWG16 cables through the cover and screw them into the V+ terminals of the high power voltage adapters on top of the cover
- Stick the GND AWG16 cables through the cover and screw them into the GND terminals of the high power voltage adapters on top of the cover
 
- Put cover on bottom and screw it in place with 8x3mm screws

# Usage

Before using the cloud chamber the first time, you need to adjust the voltage for the peltier elements.

## First time setup
- Make sure all power switches for the cooling tower are switched off
- Connect the 220V socket with a cable and plug it into mains
- Switch the 220V power switch
- The fan will start turning and the voltage displays will show the voltage they deliver to the peltier elements
- Adjust the voltage output of the voltage adapters on the case cover for the peltier elements using a screw driver and rotating the voltage adjustment clockwise. These values worked well for me:
  - Upper Peltier: 5V
  - Lower Peltier: 10.5V
- Make sure that you open up the current fully for the adapters
  - Screw the current adjustment clockwise as far as it goes

## Normal Use
- Drop 5ml of 70% isopropanol on the felt in the acrylic case
- Place a radioactive source on top of the cooling tower
- Put the acrylic case on top of the cooling tower, closing the chamber
- Switch on peltier elements
- Switch on lights
- Switch on heating element
- Wait for approx 5min
- Enjoy :)

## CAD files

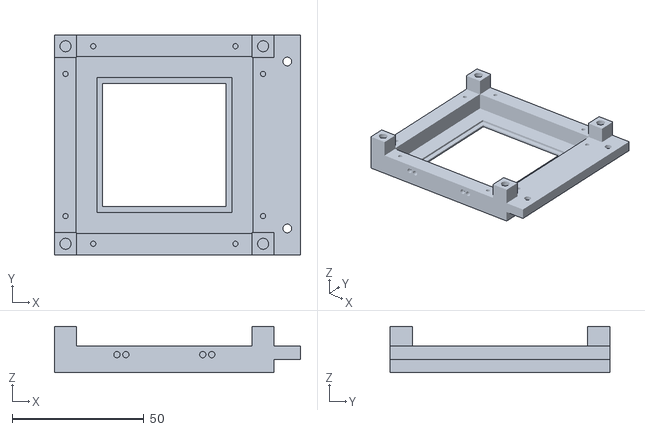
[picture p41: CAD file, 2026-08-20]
stl/cloud_chamber_cooling_plate-main_body.stl
93.4 x 83.4 x 17.5

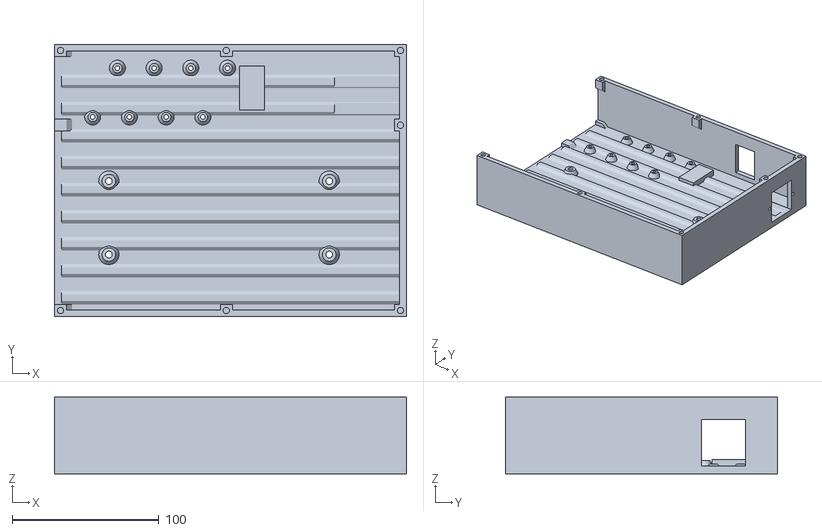
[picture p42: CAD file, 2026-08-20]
stl/cloud_chamber_power_case-lower.stl
239.6 x 185.2 x 52.4

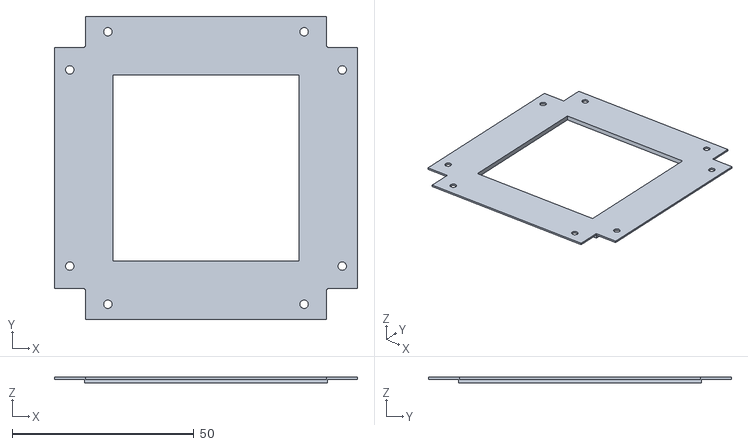
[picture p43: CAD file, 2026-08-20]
stl/cloud_chamber_cooling_plate-insulation_top.stl
83.4 x 83.4 x 1.60

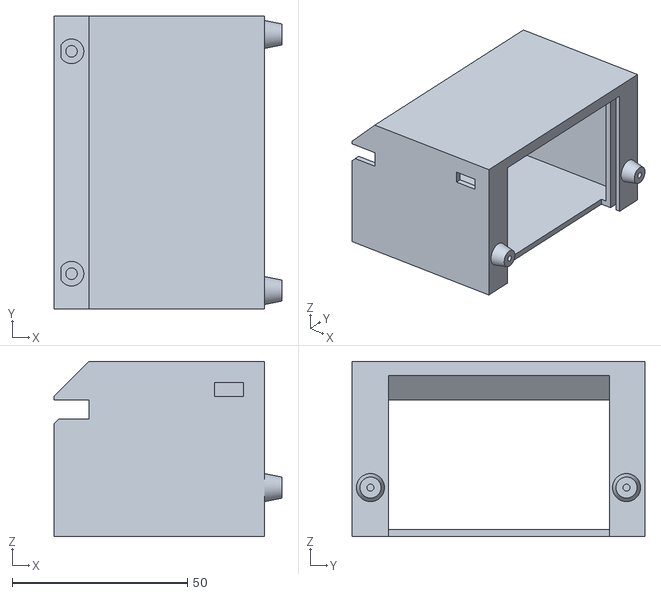
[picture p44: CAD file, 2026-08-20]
stl/cloud_chamber_light_case.stl
65.0 x 83.4 x 50.0

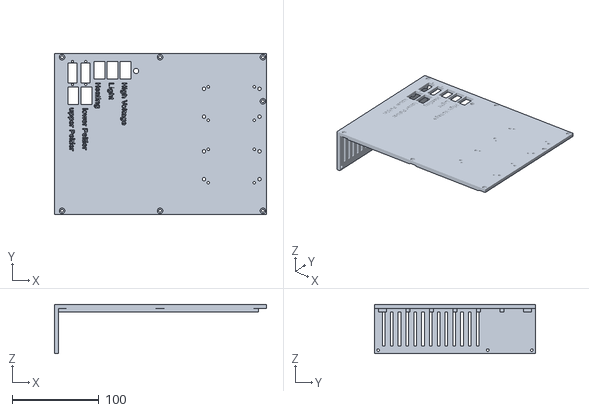
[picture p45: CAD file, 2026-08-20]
stl/cloud_chamber_power_case-upper.stl
244.2 x 185.2 x 57.0

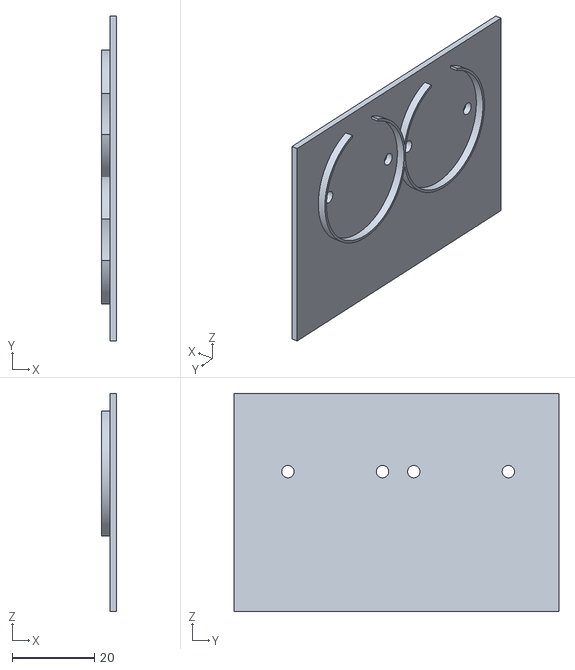
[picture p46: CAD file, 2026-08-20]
stl/cloud_chamber_led_carrier.stl
3.60 x 79.0 x 53.0

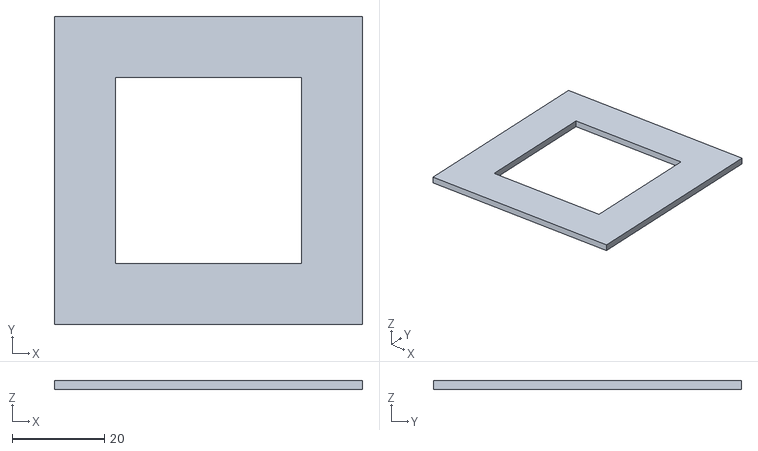
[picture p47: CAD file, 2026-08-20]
stl/cloud_chamber_cooling_plate-insulation_stencil_peltier.stl
66.8 x 66.8 x 2.00

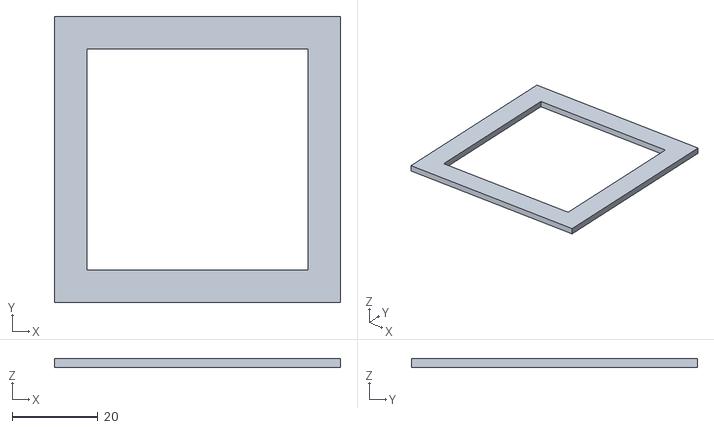
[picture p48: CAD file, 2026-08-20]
stl/cloud_chamber_cooling_plate-insulation_stencil_coppr.stl
66.8 x 66.8 x 2.00

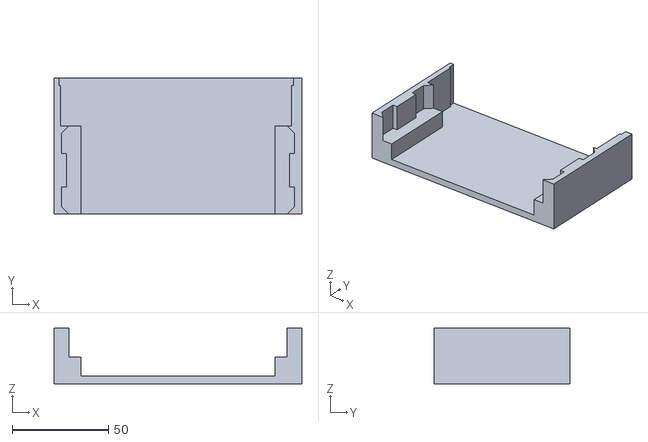
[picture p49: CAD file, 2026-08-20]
stl/cloud_chamber_top.stl
129.0 x 71.0 x 29.0

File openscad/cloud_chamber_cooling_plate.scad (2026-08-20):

$fn=256;

part="main_body";
//part="insulation_top";
//part="insulation_stencil_copper";
//part="insulation_stencil_peltier";
//part="light_connector";
//part="led_carrier";

gap = 0.2; // gap for better fitting

// cooling plate
peltier_x = 40;
peltier_y = peltier_x;

plate_height = 2;
cooling_tower_height = 11;

copper_x = 51.2;
copper_y = copper_x;

rim_width = 2.2;
rim_height = 1;

insulation_width = 8;
insulation_screw_dia = 2;

cable_distance = 36;
cable_dia = 2.4;

// insulation top
insulation_top_z = 0.6;
insulation_top_addon_z = 1;

// fan connection screws
screw_dist = 75;
screw_dia  = 4.2;
screw_height = 6;
screw_block_height = 7.5;

// acrylic cover values
cover_x = 78.6;
cover_y = 78.6;
cover_z = 5; // how deep the gap for the cover will be
cover_wall = 1.7; // how wide the gap for the cover will be

// stencil
stencil_height = 2;

// light connector
led_dia = 30;
led_x = 37;
led_screw_dia = 3;
led_screw_dist = 23;
lconnector_wall = 2;
lconnector_x = 10;
lightsloc_x = 10;
lightsloc_z = 10;
lights_y = 65;
lconnector_box_height = 50;


// calculated values
outside_x = max((screw_dist + 2*screw_dia),cover_x+2);
outside_y = max((screw_dist + 2*screw_dia),cover_y+2);
outside_height = cooling_tower_height-1;

cover_offset_x = (outside_x-cover_x)/2;
cover_offset_y = (outside_y-cover_y)/2; 

screw_off_x = (2*screw_dia)/2;
screw_off_y = screw_off_x;

insulation_screw_height = outside_height-cover_z;
insulation_screw_dist_x = screw_dist;
insulation_screw_dist_y = insulation_screw_dist_x - 2*(2.5*screw_dia);
insulation_screw_off_x = max(screw_off_x,(outside_x-insulation_screw_dist_x)/2);
insulation_screw_off_y = max(screw_off_x+2.5*screw_dia,(outside_y-insulation_screw_dist_y)/2);

outside_wall_width_x = (outside_x-copper_x)/2-insulation_width;
outside_wall_width_y = (outside_y-copper_y)/2-insulation_width;

lconnector_y = outside_y;
lconnector_z = outside_height/2;


if(part=="main_body")
{
    main_body();
    %led_carrier();
    %light_connector();
    %insulation_top();
}

if(part=="insulation_top")
{
    %main_body();
    %led_carrier();
    %light_connector();
    insulation_top();
}

if(part=="insulation_stencil_peltier")
{
    %main_body();
    %insulation_top();
    %led_carrier();
    %light_connector();
    insulation_stencil_peltier();
}
    
if(part=="insulation_stencil_copper")
{
    %main_body();
    %insulation_top();
    %led_carrier();
    %light_connector();
    insulation_stencil_copper();    
}

if(part=="light_connector")
{
    %main_body();
    %insulation_top();
    %led_carrier();
    light_connector();
}

if(part=="led_carrier")
{
    %main_body();
    %insulation_top();
    led_carrier();
    %light_connector();
}

module light_connector()
{
    translate([outside_x,0,-lconnector_box_height+outside_height+lightsloc_z+1])
    {
        difference()
        {
            cube([lconnector_x,lconnector_y,lconnector_box_height-(outside_height/2+lightsloc_z+1)-2*gap]);
            translate([0,lconnector_wall,lconnector_wall])
            {
                cube([lconnector_x,
                      lconnector_y-2*lconnector_wall,
                      lconnector_box_height-(outside_height/2+lightsloc_z+1)-2*gap-lconnector_wall]);
            }
            translate([-sqrt(2*pow(lconnector_wall,2))/2,
                           0,
                           lconnector_box_height-1.5*outside_height-sqrt(2*pow(lconnector_wall,2))/2])
            {
                rotate([0,45,0])
                {
                    #cube([lconnector_wall,lconnector_y,lconnector_wall]);
                }
            }
        }
    }
    
    translate([outside_x,0,outside_height])
    {
        // connection
        difference()
        {
            hull()
            {
                cube([lconnector_x,lconnector_y,1]);
                translate([lightsloc_x,0,lightsloc_z])
                {
                    cube([lconnector_x,lconnector_y,1]);
                }
            }
            for(i=[-1,1])
            {
                translate([lconnector_x/2,lconnector_y/2+(i*(lconnector_y/2-10)),-outside_height+3])
                {                
                    cylinder(d=3.3,h=20);
                    translate([0,0,outside_height/2+5])
                    {
                        cylinder(d=7,h=10);
                    }
                }
            }
        }
        // case
        translate([lightsloc_x,0,lightsloc_z-lconnector_box_height+1])
        {
            difference()
            {
                union()
                {
                    cube([50,lconnector_y,lconnector_box_height]);
                    for(i=[-1,1])
                    {
                        translate([50,lconnector_y/2+i*(lconnector_y/2-8/2-1.2),8/2+10])
                        {
                            rotate([0,90,0])
                            {
                                cylinder(d1=8,d2=6,h=5);
                            }
                        }
                    }
                }
                
                for(i=[-1,1])
                {
                    translate([50-lconnector_wall,lconnector_y/2+i*(lconnector_y/2-8/2-1.2),8/2+10])
                    {
                        rotate([0,90,0])
                        {
                            cylinder(d1=3.2,h=5+lconnector_wall);
                        }
                    }
                }
                translate([0,lconnector_wall,lconnector_wall])
                {
                    cube([50-3*lconnector_wall,lconnector_y-2*lconnector_wall,lconnector_box_height-2*lconnector_wall]);
                    translate([50-2*lconnector_wall,0,-lconnector_wall])
                    {
                        cube([lconnector_wall+2*gap,lconnector_y-2*lconnector_wall,lconnector_box_height-lconnector_wall]);
                        translate([-2*lconnector_wall,(14/2)*1.2,-lconnector_wall])
                        {
                            cube([4.1*lconnector_wall,lconnector_y-17*1.2,lconnector_box_height-lconnector_wall]);
                        }
                        
                    }
                }
                translate([50-7.1*lconnector_wall,0,lconnector_box_height-5*lconnector_wall])
                {
                    #cube([4.1*lconnector_wall,lconnector_wall,2*lconnector_wall]);
                }
            }
        }
    }
}
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

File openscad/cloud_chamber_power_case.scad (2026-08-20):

$fn=128;

part = "lower";
//part = "upper";

power_x = 230;
power_y = 116;
power_z = 30;
power_screw_dia = 4.6;
power_screw_x = 150;
power_screw_y = 50;
power_screw_off_x = 32;
power_screw_off_y = 33;
power_addon_y = 60;
power_addon_x = 5;

case_wall = 4.6;

dcdc_x = 60;
dcdc_y = 52;
dcdc_z = 31;
dcdc_screw_dia = 3;
dcdc_screw_x = 53;
dcdc_screw_y = 38.5;
dcdc_screw_off_x = 3;
dcdc_screw_off_y = 5.8;

dclow_x = 51;
dclow_y = 23;
dclow_z = 1;
dclow_screws = [[40.5,3.2,0],[7.25,20,0]];
dclow_screw_dia = 3.2;

wagobase_x = 17;
wagobase_y = 30;
wagobase_z = 10;

plug_outside_x = 45;
plug_x = 30;
plug_y = 31.4;
plug_z = 52;
plug_screw_dist = 35;
plug_screw_dia = 3;

power_switch_z = 30;
power_switch_y = 32;
power_switch_x = 22;

voltage_display_x = 10.4;
voltage_display_y = 22.8;
voltage_display_z = 7;
voltage_display_screw_dia = 2.6;
voltage_display_screws = [[5.5,-1.8],[5.5,24.7]];

switch_low_x = 12.6;
switch_low_y = 20;
switch_low_z = 20;
switch_low_gap = 2.5;

air_gap_width = 3;

screw_block_screw_dia = 3.2;
screw_block_x = screw_block_screw_dia+5;
screw_block_y = screw_block_x;
screw_block_z = screw_block_x;

cables_fan_dia = 6;

power_addon_z = case_wall + screw_block_z + 5;
case_y = power_y + power_addon_y;
case_z = power_z + power_addon_z;
case_x = power_x + power_addon_x;


power_loc = [case_wall+5,screw_block_y+1,0];
plug_loc = [case_x+3+2*case_wall,case_y-plug_outside_x-5,plug_y+case_wall+1];
plug_rot = [270,0,90];
wagobase_loc = [case_x-power_switch_x+case_wall-plug_z-wagobase_x-18,case_y-wagobase_y+case_wall-10,0];
dclow_loc1 = [case_x-power_switch_x+case_wall-plug_z-40,case_y-dclow_x+case_wall-1,0];
dclow_loc2 = [case_x-power_switch_x+case_wall-plug_z-42-dclow_y,case_y-dclow_x+case_wall-1,0];
dclow_loc3 = [case_x-power_switch_x+case_wall-plug_z-44-2*dclow_y,case_y-dclow_x+case_wall-1,0];
dclow_loc4 = [case_x-power_switch_x+case_wall-plug_z-46-3*dclow_y,case_y-dclow_x+case_wall-1,0];
power_switch_loc = [case_x-power_switch_x+case_wall-plug_z,case_y-power_switch_y+2*case_wall,2*case_wall];
dcdc_loc1 = [case_x+2*case_wall-dcdc_x-10,(case_y+2*case_wall-dcdc_y)/2-dcdc_y/2-10,case_z+case_wall];
dcdc_loc2 = [case_x+2*case_wall-dcdc_x-10,(case_y+2*case_wall-dcdc_y)/2+dcdc_y/2+10,case_z+case_wall];
voltage_display_loc1 = [case_wall+switch_low_gap+screw_block_x,
                        -1.8+case_y-voltage_display_y,
                        case_z+2*case_wall-voltage_display_z];
voltage_display_loc2 = [case_wall+switch_low_x+(2*switch_low_gap)+screw_block_x,
                        -1.8+case_y-voltage_display_y,
                        case_z+2*case_wall-voltage_display_z];
switch_low_loc1 = [case_wall+switch_low_gap+screw_block_x,
                   -1.8-voltage_display_y+case_y-switch_low_y-case_wall,
                   case_z+2*case_wall-switch_low_z];
switch_low_loc2 = [case_wall+switch_low_x+(2*switch_low_gap)+screw_block_x,
                   -1.8-voltage_display_y+case_y-switch_low_y-case_wall,
                   case_z+2*case_wall-switch_low_z];
switch_low_loc3 = [case_wall+2*switch_low_x+(3*switch_low_gap)+screw_block_x,
                   case_y-switch_low_y,
                   case_z+2*case_wall-switch_low_z];
switch_low_loc4 = [case_wall+3*switch_low_x+(4*switch_low_gap)+screw_block_x,
                   case_y-switch_low_y,
                   case_z+2*case_wall-switch_low_z];
switch_low_loc5 = [case_wall+4*switch_low_x+(5*switch_low_gap)+screw_block_x,
                   case_y-switch_low_y,
                   case_z+2*case_wall-switch_low_z];
                   
cables_fan_loc = [94,case_y+2*case_wall-20,case_z];
switch_underplate_x = 5*(switch_low_x+switch_low_gap);
switch_underplate_y = switch_low_y+voltage_display_y+3*case_wall+2;
switch_underplate_z = case_wall;
switch_underplate_loc = [case_wall+screw_block_x,case_y-switch_underplate_y+case_wall+0.1,case_z];


if(part=="lower")
{
    lower_case();
    %upper_case();
}
if(part=="upper")
{
    %lower_case();
    upper_case();
}
if(part=="parts")
{
    screw_block(negative=true);
    screw_block(negative=false);
}

module upper_case()
{
    difference()
    {
        union()
        {
            // front
            cube([case_wall,case_y+2*case_wall,case_z+case_wall]);
            // top
            translate([0,0,case_z+case_wall])
            {
                cube([case_x+2*case_wall,case_y+2*case_wall,case_wall]);
                // indents left and right
                for(i=[case_wall+screw_block_x+1,case_x/2+screw_block_x+1])
                {
                    translate([i,case_wall,-case_wall])
                    {
                        difference()
                        {
                            cube([case_x/2-screw_block_x-case_wall-2,case_y,case_wall]);
                            translate([0,case_wall,0])
                            {
                                cube([case_x/2-screw_block_x-case_wall-2,case_y-2*case_wall,case_wall]);
                            }
                        }
                    }
                }
                // reenforcments
                for(i=[screw_block_y+1:
                       (case_y+case_wall-2*screw_block_y-2)/6:
                       case_y+2*case_wall])
                {
                    translate([0,i,-case_wall])
                    {
                        #cube([case_x+2*case_wall-screw_block_x-1,case_wall,case_wall]);
                    }
                }
            }
        }
        place_parts(negative=true);
        air_gaps();
    }
}


module lower_case()
{
    difference()
    {
        union()
        {   
            translate([case_wall,0,0])
            {
                difference()
                {
                    cube([case_x,case_y,case_z]+[case_wall,2*case_wall,case_wall]);
                    translate([0,case_wall,case_wall])
                    {
                        cube([case_x,case_y,case_z]);
                    }
                }
            }
            reenforce_bars(offset=screw_block_x,length=case_x-case_wall-0.3);
            place_parts();
        }
        place_parts(negative=true);
    }
}

module place_parts(negative=false)
{
    translate(power_loc)
    {
        power(negative=negative);
    }
    translate(plug_loc)
    {
        rotate(plug_rot)
        {
            plug(negative=negative);
        }
    }
    translate(wagobase_loc)
    {
        wagobase(negative=negative);
    }
    for(i=[dclow_loc1,dclow_loc2,dclow_loc3,dclow_loc4])
    {
        translate(i)
        {
            dclow(negative=negative);
        }
    }
    translate(power_switch_loc)
    {
        power_switch(negative=negative);
    }
    for(i=[dcdc_loc1,dcdc_loc2])
    {    
        translate(i)
        {
            dcdc(negative=negative);
        }
    }
    for(i=[switch_low_loc1,switch_low_loc2,switch_low_loc3,switch_low_loc4,switch_low_loc5])
    {
        translate(i)
        {
            switch_low(negative=negative);
        }
    }
    for(i=[voltage_display_loc1,voltage_display_loc2])
    {
        translate(i)
        {
            voltage_display(negative=negative);
        }
    }
    translate(cables_fan_loc)
    {
        cables_fan(negative=negative);
    }
    translate(switch_underplate_loc)
    {
        switch_underplate(negative=negative);
    }
    place_text(negative=negative);
    place_screw_blocks(negative=negative);
}

module air_gaps()
{
    for(i=[2*case_wall:3*air_gap_width:power_y+power_loc[1]])
    {
        translate([0,i,2*case_wall])
        {
            #cube([case_wall,air_gap_width,case_z-2*case_wall]);
        }
    }
}

module place_screw_blocks(negative=false)
{
    //front row
    for(i=[0,power_y+power_loc[1]+1,case_y+2*case_wall-screw_block_y])
    {
        translate([case_wall,i,screw_block_x])
        {
            rotate([0,90,0])
            {
                screw_block(negative=negative);
            }
        }
    }
    //back row
    for(i=[0,power_y+power_loc[1]+1,case_y+2*case_wall-screw_block_y])
    {
        translate([case_x-screw_block_x+2*case_wall,i+screw_block_y,case_z+case_wall])
        {
            rotate([180,0,0])
            {
                screw_block(negative=negative);
            }
        }
    }
    //right side
    for(i=[screw_block_x+case_wall,screw_block_x+case_x/2])
    {
        translate([i,screw_block_y,case_z+case_wall])
        {
            rotate([0,180,90])
            {
                screw_block(negative=negative);
            }
        }
    }
    //right side
    for(i=[case_wall,case_x/2])
    {
        translate([i,-screw_block_y+case_y+2*case_wall,case_z+case_wall])
        {
            rotate([0,180,270])
            {
                screw_block(negative=negative);
            }
        }
    }
}
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

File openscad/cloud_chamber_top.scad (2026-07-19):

wall = 4;
gap = 0.2;
cooler_x = 121;
cooler_y = 46;
cooler_z = 25;
cooler_45 = 6;
cooler_gap_x = 2.6;
cooler_gap_y = 17;
cooler_pins_offset_x = 10;
cooler_pins_z = 10;
fan_x = 120;
fan_y = 25;
fan_z = 25;
fan_hook_x = 1;
fan_hook_y = 4;
minkovsky_offset=(sqrt(pow(cooler_45,2)+pow(cooler_45,2)))/2;

cooler_case();

module cooler_case()
{
    difference()
    {
        cube([cooler_x+2*wall,cooler_y+fan_y,cooler_z+wall]);
        translate([wall,0,wall])
        {
            cooler();
        }
        translate([wall-abs(cooler_x-fan_x)/2,cooler_y,wall])
        {
            fan();
        }
    }
}

module fan()
{
    cube([fan_x,fan_y,fan_z]);
    translate([-fan_hook_x,fan_y-fan_hook_y,0])
    {
        cube([fan_x+2*fan_hook_x,fan_hook_y,fan_z]);
    }
}

module cooler()
{
    difference()
    {
        cooler_block();
        cooler_cutout();
    }
}

module cooler_block()
{
    // pins
    translate([cooler_pins_offset_x,0,0])
    {
        cube([cooler_x-2*cooler_pins_offset_x,cooler_y,cooler_pins_z]);
    }
    // cooler    
    translate([minkovsky_offset-gap,-gap,cooler_pins_z])
    {
        minkowski()
        {
            cube([cooler_x-2*minkovsky_offset+2*gap,cooler_y-2*minkovsky_offset+2*gap,(cooler_z-cooler_pins_z)/2]);
            rotate([0,0,45])
            {
                cube([cooler_45,cooler_45,(cooler_z-cooler_pins_z)/2]);
            }
        }
    }
}

module cooler_cutout()
{
    for(i=[-gap,cooler_x-cooler_gap_x])
    {
        translate([i,(cooler_y-cooler_gap_y)/2-gap,0])
        {
            cube([cooler_gap_x+gap,cooler_gap_y+gap,cooler_z]);
        }
    }
}

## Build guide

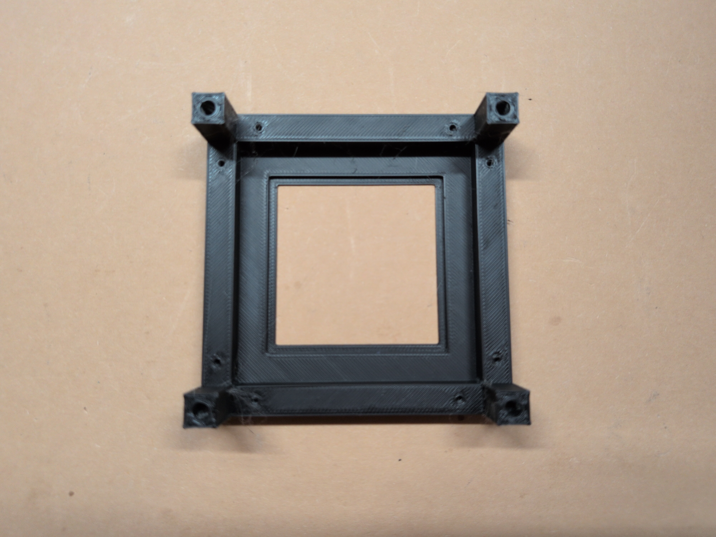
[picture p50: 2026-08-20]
images/assembly/5d_cooling_tower.jpg

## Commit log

2026-08-20 Add images of finished cloud chamber
2026-08-20 Add stl files
    [cloud_chamber_cooling_plate-insulation_stencil_coppr.stl, cloud_chamber_cooling_plate-insulation_stencil_peltier.stl, cloud_chamber_cooling_plate-insulation_to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]
2026-08-20 Add light support to openscad files
    [cloud_chamber_cooling_plate.scad, cloud_chamber_power_case.scad]
2026-08-21 Add Schematic for cooling tower
2026-08-21 Switch md image links for html img tags
2026-08-26 Add links to stl files
2026-08-26 Add warning about mains voltage
2026-08-26 Update base assembly instructions
2026-08-31 fix: correct typos and syntax errors in README.md
    - Fix 'dealng' -> 'dealing'
    - Fix 'accordings' -> 'accordance' (with 'to')
    - Fix 'therefor' -> 'therefore'
    - Fix capitalization 'Adjust Voltages' -> 'adjust voltages'
    - Fix duplicate text 'adjusting the voltages' in table
    - Fix 'Please not that' -> 'Please note that
2026-08-31 fix: additional typo corrections in README.md
    - Revert incorrect 'accordance' back to 'according'
    - Restore 'adjusting the voltages' in the Voltage Meter bullet
    - Revert 'wrongfully' back to 'wrongly'
    - Revert lowercased section title back to '2. Adjust Voltages'
    - build -> built, lose -> loose (4x), the the -> the,
    was taking -> was taken, moandatory -> mandatory,
    Usual -> Usually, condutivity -> conductivity,
    LEDspot -> LED spot, screws is -> screws if necessary,
    wirse -> wires, tarts -> start, coltage -> voltage,
    adjustent -> adjustment, clock wise -> clockwise (2x),
    leating -> heating
